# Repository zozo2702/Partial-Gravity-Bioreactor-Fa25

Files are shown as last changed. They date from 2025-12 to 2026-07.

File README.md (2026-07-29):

# Partial Gravity Bioreactor Simulation

A computational simulation of a partial gravity bioreactor system designed to model biological behavior under reduced gravity conditions.

🏆 Developed as a **Senior Design Project (1st Place Winner)**

---

## Overview

This project focuses on simulating how cells and biological systems behave in environments where gravity is altered, such as in space or rotating bioreactor systems.

The model incorporates:

* Rotational dynamics
* Gravity vector manipulation
* Mathematical modeling of system behavior

## Key Features

* Simulation of partial gravity conditions
* Mathematical modeling of rotational systems
* Data visualization of system behavior
* Modular code structure for experimentation

## Applications

* Space biology research
* Tissue engineering
* Bioreactor design optimization
* Microgravity simulation studies

## Authors

** Zenub Abouzid- Led simulation and mathematical modeling of the system
** Irene Bui- Experimental design
** Jake Fisher- SolidWorks (CAD)
** Dmitry Hackel- Hardware construction

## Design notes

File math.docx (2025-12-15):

To construct the prototype, specific calculations must be performed. These calculations will be utilized for simulation purposes to validate the prototype. To generalize the calculation, the specimen will be referred to as a particle; however, this term also applies to cells and the samples used during validation. Due to the numerous considerations involved in the calculation, the process will be divided into five sections: the inclined plane, sedimentation velocity, angular velocity, revolutions per minute, and cellular portion.

### Incline Plane

The inclined plane facilitates the reduction of the gravitational force exerted on a particle by decomposing it into components. The gravitational force is entirely on one axis when

$$ \theta= 0^\circ \text{ or } 90^\circ $$

or decomposed into components. Utilizing trigonometry, Eq. 1 and Eq. 2 illustrate the values for the parallel and perpendicular components of gravity relative to the plane.

$$ g_{\parallel y}= g \, \sin \theta^\circ (1) $$

##### Equation 1. Parallel Gravitational Component

Where:

$$

g_{\parallel y}= \text{gravitational component parallel to the plane}

$$

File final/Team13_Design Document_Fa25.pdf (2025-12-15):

I

# Temple University

## College of Engineering

## Bioengineering

## Design Document

## Partial Gravity Bioreactor

## Presented By: Team #13

Dmitry M Hackel | Irene Bui
Jake Fisher | Zenub Abouzid

## Supervised By:

## Dr. Yah-el Har-el & Dr. Peter Lelkes

1 2 | – | 0 8 | – | 2 025

II

## Acknowledgment

We want to extend our most profound appreciation to the following individuals and organizations who have contributed to the completion of this project:

- Dr. Jonathan Gerstenhaber, for providing valuable information on previous prototypes, coding, debugging, and ideas that paved the way for the prototype, and for delivering his lab time and office hours for us to finalize our prototype.
- Dr. Michael Phelan, for allowing us to use his air-bubble-bioreactor
- Dr. James Furmato, for allowing us to use the laboratory during his lectures.
- PhD Candidate Jennifer Patten and PhD Student Shaylyn Westmoreland, for providing the materials in the lab and being present to supervise the laboratory validation test.
- Brian Amin and Matthew Short, a previous team who completed a similar topic, for giving us the time to explain their prototype in more depth.
- Ahmed Satour and Muhammed Hassan, for aiding in the program.
- The 2nd floor mechanical shop, lab coordinators, and students who kindly helped us with the issues faced during the build.
- Temple University, for providing access to their machines, labs, and space.

Additionally, we would like to express our gratitude to all those who have supported us in both visible and unseen ways. Without your contributions and presence, this project would not have been possible.

Thank you.

III

## Abstract

The progress of human exploration to space, the Moon, and Mars is not considered safe because of the limited understanding of how partial gravity impacts human cells. This issue has not been fully addressed due to cost limitations and the lack of validation of partial gravity on Earth. This project focused on developing a validated prototype for a partial gravity bioreactor. By successfully simulating the mathematical model and conducting tests to validate the prototype, a better understanding of whether partial gravity is achieved and its limitations can be discussed.

IV

# Table of Contents

## LIST OF ACRONYMS/ABBREVIATIONS | VI LIST OF FIGURES | I LIST OF TABLES | II

V

VI

### List of Acronyms/Abbreviations

MOND | Modified Newtonian Dynamics
ACME | Advanced Combustion via Microgravity Experiments
NASA | The National Aeronautics and Space Administration
ISS | International Space Station
0G | Zero Gravity
µG | Microgravity

1
6 G | Lunar Gravity

3
8 G | Martian Gravity
1G | Earth Gravity
RWV | Rotating Wall Vessel
UNSDG | United Nations Sustainable Development Goals
SDG | Sustainable Development Goals
DGD | Degree of Gravity Dispersion
RGP | Reduced Gravity Paradigm
STLV | Slow-Turning Lateral Vessel
HARV | High Aspect Ratio Vessel

MAGICIAN Mars Artificial Gravity Habitat with Centrifugation

I

### List of Figures

II

### List of Tables

# 1. Problem Statement

## 1.1 Overall Objective

Since the 1960s, space exploration has yielded intriguing discoveries that continue to unfold. Yuri Gagarin became the first human in space in 1961, paving the way for thousands of astronauts and cosmonauts to follow him as the years passed [1]. Various theories have been proposed based on space, including the Croatian Barrel Theory, which explains how the solar system, stars, and other celestial bodies formed [2], [3]. In 2002, research refuted the theory that gravity alone governs the universe, as it could not explain specific astronomical observations [4]. Sanders and McGaugh modified Newtonian gravity as an alternative to cosmic dark matter, known as Modified Newtonian Dynamics (MOND), correlating the Newtonian acceleration with the observed acceleration at any radius in a galaxy [5], [6].

Exploring space not only reveals discoveries beyond our planet but also uncovers truths that shape and govern our lives. Advanced Combustion via Microgravity Experiments (ACME) investigates fuel efficiency and pollutant production in combustion under microgravity conditions on Earth [7]. One of their investigations, Flame Design, studied the quantity of soot produced under different flame conditions [7]. Such a discovery could lead to more efficient combustion, reducing pollution on Earth [7]. In the ongoing Moon exploration, researchers found that the Moon's gravity affects Earth’s tides, plant growth, animal behavior, and agricultural practices [8]. Moreover, models have shown that the Earth-Moon coupled magnetospheres provide a buffer against the solar wind, allowing for a reduction in Earth’s atmospheric loss to space [9]. The National Aeronautics and Space Administration (NASA) has been exploring Mars for over sixty years to decide whether it is or was a habitable world [10]. Since Mars is the most similar planet to Earth, understanding its surface and evolution is crucial for preparing for future human exploration [11]. With evidence suggesting that Mars was once full of water, warmer, and had a thicker atmosphere, it is highly likely that Mars could be a habitable environment [11].

Traveling beyond Earth’s atmosphere to investigate potential extraterrestrial life entails considerable risks and substantial financial investment. Given that human physiology is heavily dependent on gravity, significant fluctuations in the gravitational force may lead to serious health issues [12]. Gravity, as a vector quantity, influences all objects by determining their weight relative to their mass [13]. Biological organisms respond to environmental stimuli—including gravity—by developing unique morphological traits, physiological characteristics, behaviors, and habitat preferences [13]. The sensitivity of organisms to changes in gravity increases with their size and mass, with single cells enduring exposures up to 10⁵G and humans tolerating gravitational forces of 4-5G [13]. At the cellular level, cells comprise organelles, each with mass and thus subject to gravitational forces [14]. Variations in gravitational vectors could disrupt cellular homeostasis, affecting structural integrity, composition, and orientation, such as the cytoskeleton, which maintains cellular shape [14]. Additionally, numerous studies have documented genes that are sensitive to gravity alterations, including alterations in cytoskeletal gene expression pathways and gene inhibition following microgravity exposure [15], [16]. In the absence of gravity, cellular growth pathways shift, and metabolic processes adapt due to changes in reactive oxygen species levels [17], [18].

Furthermore, cellular adaptation to gravity is crucial for tissue adaptation, as bones contain osteocytes that sense and respond to varying gravitational loads [13].

Such cellular changes impact the entire human system. Astronauts exposed to microgravity undergo physiological deconditioning in systems sensitive to mechanical loading, including the cardiovascular, pulmonary, and musculoskeletal systems [19]. To mitigate these effects, International Space Station (ISS) crew members engage in rigorous exercise; however, despite extensive physical activity, astronauts still return from their six-month ISS missions exhibiting decreased calf muscle volume and strength, loss of bone mineral density, and reduced peak oxygen uptake [20], [21], [22], [23].

Given that, it is highly unethical to send people into space without understanding the effects of gravitational changes on the body. This paper discusses a validated prototype of a device that cultures cells under partial gravity and microgravity, enabling the correlation of specific cell behaviors with gravitational conditions.

## 1.2 Background

Understanding the effects of partial gravity on humans is less well studied due to the high costs of conducting tests in partial or microgravity environments. Between 1960 and 1973, the research experience and studies gained during the Apollo missions—focused on lunar exploration—provided valuable insights into the diverse effects of partial gravity on the human musculoskeletal, cardiovascular, and respiratory systems, employing either microgravity or Earth’s gravity as controls [23], [24]. However, the Apollo missions cost approximately $25.4 billion in 1969, equivalent to roughly $217 billion in 2024 [25]. Following these missions, despite the lack of subsequent lunar landings, the failures in early missions facilitated advancements in spacecraft design, including the incorporation of additional protective layers and the development of new, safer materials, as well as the integration of computer systems for troubleshooting purposes [26]. In 2019, the health impacts of a year-long space mission were examined at both the molecular and psychological levels by comparing the DNA sequences of twin brothers, Mark and Scott Kelly, with Mark Kelly remaining on Earth serving as the control, and Scott Kelly participating in spaceflight [27], [28]. The study revealed that extensive changes in multisystem and gene expression occur during spaceflight [28]. Astronauts may face risks including mitochondrial dysfunction, immunological stress, vascular modifications, fluid shifts, and cognitive performance decline, as well as alterations in telomere length, gene regulation, and genome integrity [28].

Given the costs and decommissioning of the ISS, researchers endeavored to replicate partial gravity conditions on Earth, such as using a pulley-spring system to simulate partial gravity for rodents (see Figure
1) [23], [29]. However, a limitation of the apparatus was that only the tail was suspended rather than the entire body, resulting in a weight shift within the rodent’s body and thus failing to provide a truly accurate simulation [29].

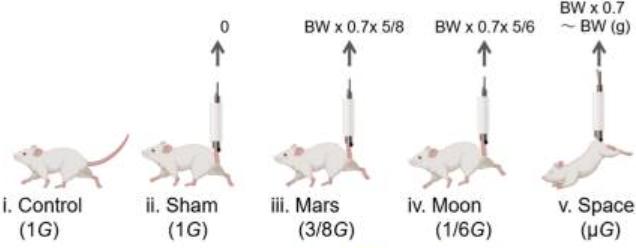
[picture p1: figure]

Figure 1. Experimental Design for Simulated Partial Gravity Apparatus for Rats
The figure shows the groups of experimental rats with (i) the Control group (1G); (ii) the sham group with SA (1G); (iii) the Mars group (³
8

G); (iv) the Moon group (¹
6

G); and (v) the interplanetary space (µG) group [29].

The effects of gravity on an object may manifest as either displacement or deformation [30]. Microgravity creates distinctive environments conducive to cell growth, whereas partial gravity (such as on the Moon and Mars) may yield markedly different effects [31]. To comprehensively understand the concepts related to partial gravity apparatuses, it is imperative to distinguish between zero gravity, gravity, microgravity, and partial gravity. Gravity is an abstract phenomenon that can be quantified; however, its fundamental cause remains unknown [32]. The gravitational constant is not a force or acceleration but is employed as a scaling factor in Newton's Law of Gravitation, as demonstrated in Equation 1[32], [33].

F =

Gm1m2
r

2

(1)

Equation 1. Gravitational Force Equation

Where:
F = gravitational force
m1 = mass 1
m2 = angle between the inclined plane and the base r = distance between masses
G | = universal constant (6.67384 ∗ 10⁻¹¹ m³ s
| 2 kg

)

Zero gravity (0G) describes a condition where there is an absence of gravitational force exerted on an object, which occurs either due to its infinite distance from any other gravitational body or when the net sum of all forces acting upon it equals zero [34]. Microgravity (μG) pertains to a state in which the net gravitational force exerted on an object is minimal, typically within the range of 10⁻⁴

to 10⁻⁶G [35].
Although the object remains under the influence of gravitational forces, it continues to undergo free fall [35]. This perpetual free fall occurs when an object falls at a constant velocity without contacting a surface [35]. As a result, the difference between the initial and final velocities manifests as a constant acceleration (g) [35]. Partial gravity refers to a gravitational force that is diminished but not absent compared to Earth's gravitational acceleration, such as on the Moon, where gravity is approximately 1
6

G, on Mars 3
8

G, and on

Earth 1G [27]. On Earth, partial-gravity simulation can be achieved using techniques such as centrifugation, parabolic flight, or modified rotation devices that generate accelerations below 1 g [36].

To investigate gravitational effects, cell culturing is regarded as the most efficacious method, with bioreactors serving as the optimal apparatus, given their ability to supply controlled nutrients and biomimetic stimuli for cellular growth [37]. A bioreactor is defined as a vessel in which a chemical process involving organisms or biochemically active substances derived from such organisms is conducted, or a system designed for cell cultivation, first developed in 1964 (refer to Figure 2).

Figure 2. Basic Bioreactor

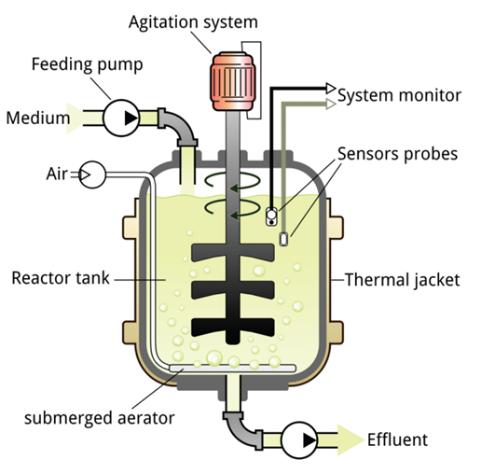
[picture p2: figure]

The figure shows the basic components of a bioreactor. It includes a feeding pump, air, medium, an agitation system, a reactor tank, and other elements to ensure an automated culturing system.

Previous bioreactors were designed as ground-based systems to mimic aspects of weightlessness or reduced gravity experienced by biological organisms in space. Recognizing this potential, in the mid-1980s, NASA researchers at the Johnson Space Center needed to develop a method to study the effects of microgravity on human tissues, as the shuttle fleet was grounded following the Challenger disaster [38]. They invented a rotating bioreactor to address the challenge of treating injured astronauts in space and to simulate weightlessness on Earth [38]. In μG, the bioreactor enables cells to grow in three-dimensional tissue structures that closely resemble natural development, facilitating advances in medicine both on Earth and in space [38]. In 2002, Houston-based Regenetech Inc. licensed NASA bioreactor technology and patents that can expand adult stem cells (from blood to bone marrow) by 50-200 times in less than a week, providing safer, faster, and more affordable cell sources for therapies [38].

Partial gravity bioreactors, although not extensively studied, have been previously examined. Research dating back to the 1900s has investigated the effects of clinostats, or rotating wall vessels, on biological samples [39]. Clinostats were invented by Julius Sachs, who rotated growing plants around their growth axis [39]. These devices exist in one-dimensional (1-D) or two-dimensional (2-D) forms, depending on the dimensions of the rotated axial line or the entire experimental area [40]. Subsequently, enhancements to the clinostat with two axes led to the development of three-dimensional (3-D) clinostats, known as the Random Positioning Machine (RPM) (refer to Figure 3) [40], [41].

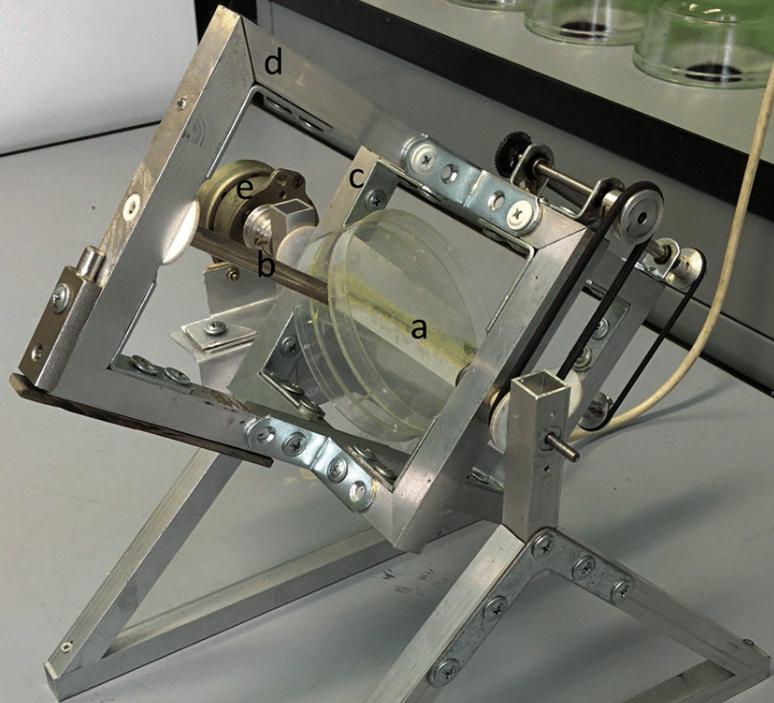
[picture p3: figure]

Figure 3. 3D Clinostat
The figure depicts a three-dimensional clinostat employed to investigate the effects of microgravity on seed germination: (a) insert for Petri dishes; (b) rotating shaft; (c) inner frame; (d) outer rotating frame; (e) motor [41].

Numerous early-stage partial-gravity bioreactors have been investigated using plant species capable of continuous growth under Earth's gravity [42]. Initial implementations included clinostats, which maintain a constant rotation of a sample to average the gravitational vector to near zero, effectively [39]. This partial gravity bioreactor does not fully replicate “true” microgravity, as cells continue to experience mechanical stimulation and gradients that differ from those in actual microgravity conditions [39]. Subsequently, rotating wall vessel (RWV) bioreactors were introduced as a specialized variant of clinostats [39]. RWVs are fluid-filled cylinders containing cells, designed to create a low-shear, controlled environment conducive to cellular differentiation in three-dimensional space [43]. By rotating at a terminal velocity, RWVs facilitate the proper delivery of nutrients to the tissue culture, thereby promoting healthy tissue and cell growth [45]. (https://www.nature.com/articles/nm0898-901) In 2018, a previous senior design team utilized the stability of RWVs for cell culturing while incorporating the partial gravity factor using an inclined plane to partially cancel the gravitational vector, allowing cells to experience a form of partial gravity (refer to Figure 4).

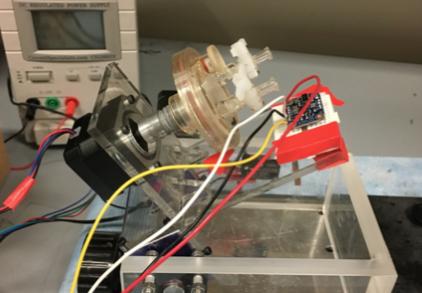
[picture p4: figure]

Figure 4. Partial Gravity Bioreactor
The figure depicts the prototype of a partial gravity bioreactor, designed by an earlier senior design team. It comprises an RWV affixed to an inclined plane that simulates partial gravity.

## 1.3 Needs Statement

There is a need to build a validated partial gravity cell-culturing prototype that would enable us to study the relationship between cell properties and different gravitational environments, thereby allowing us to correlate gravitational differences with cell properties.

## 1.4 Implications of Project Success

If the prototype succeeds, both terrestrial and extraterrestrial life would benefit significantly. Understanding the effects of varying gravitational conditions on cellular behavior would enable more precise conclusions about human space exploration. Such findings would underpin the development of solutions to safeguard human safety beyond Earth. Facilitating human travel to outer space, including destinations such as Mars and the Moon, enhances our understanding of extraterrestrial regions and addresses fundamental questions about alien life. Additionally, this research has the potential to identify new planets or locations in space where humans might establish a new life.

The success of the prototype closely correlates with several United Nations Sustainable Development Goals (UNSDGs) [44]. SDG 3: Good Health and Well-being is supported, as the device facilitates controlled studies on how partial gravity influences cellular development, physiology, and long-term health in space [45]. By understanding these effects, the prototype can inform the design of countermeasures, treatments, and potentially therapeutic approaches for conditions such as bone loss and muscle atrophy, which are of critical concern for astronauts [28]. Accordingly, the prototype would help ensure healthy lives for humans [45]. Furthermore, SDG 9: Industry, Innovation, and Infrastructure is pertinent, as the development of the prototype constitutes an innovative research platform that represents the convergence of biotechnology and space technology [46]. Additionally, the prototype advances SDG 12: Responsible

Consumption and Production by implementing a closed-loop biological system, an approach essential for sustainable space habitats and beneficial for the efficient utilization of resources on Earth [47]. The use of a bioreactor enhances system control during cell cultivation, enabling accurate, real-time monitoring, early problem detection, reproducibility, and cost efficiency [48]. In this context, SDG 13: Climate Action is addressed by demonstrating how biological systems adapt to extreme and changing environments, thereby informing strategies for Earth's ecosystems [49].

# 2. Design Criteria

To guarantee the feasibility of the prototype, the design criteria are classified as either non-negotiable (mandatory) (refer to Table 1) or negotiable (desirable) (refer to Table 2). However, owing to the complexity of the project, these criteria are divided into two primary domains: partial gravity and the prototype.

## 2.1 Non-Negotiable Criteria

Three criteria must be satisfied to deem the partial gravity component in the project successful: gravitational type, uniform trajectory, and mathematical simulation.

Gravitational Type: With NASA deorbiting the ISS, the ability to conduct experiments in the unique microgravity laboratories would be impossible. Therefore, gravitational experiments conducted on Earth should encompass the primary missions previously planned. According to NASA, traveling to the lunar surface and around the Moon would facilitate scientific discoveries that prepare humans for subsequent exploration, including Mars [50]. As the Moon and Earth represent the two most significant gravitational environments, lunar gravity (¹
6

G) and Martian gravity (³
8

G) warrant careful consideration [51]. To obtain

more accurate data, Earth’s gravity (1G) and microgravity (μG) should also be included to ensure that the same cells are subjected to all gravity levels and to serve as references for previous experiments [51].

Uniform Trajectory: To cultivate cells effectively, the partial gravity method should not present any issues for cell culture practices. Given cells' high sensitivity to their environment, the technique used to simulate partial gravity must prevent excessive vibrations or inconsistent cell motion [52]. To accomplish this, the procedure for attaining different gravitational levels should function smoothly, enabling cells to undergo free fall while simultaneously minimizing shear stress on the cells and maintaining these conditions continuously.

Mathematical Simulation: The partial gravity effect on cells has not yet been observed or tested. However, visualizing gravity is not applicable, since gravity is a theory [53]. Utilizing mathematics, fluid mechanics, and particle mechanics, a mathematical model should be developed for partial gravity.

Four criteria should be met to consider the prototype successful: overall device size, electrical safety, emergency safety, and material.

Overall Device Size: Since the prototype's placement may be limited to the incubator, its overall dimensions are also constrained. The Nuaire NU-5810E incubator is considered the most suitable and effective location based on previous designs because it operates at 37°C with 98% humidity [54]. The maximum size of the prototype is limited by the incubator's internal capacity, which measures 23 × 17 × 14 in.

Electrical Safety: For electrical safety, the standards established by the International Electrotechnical Commission (IEC), specifically IEC 60204-1, which outlines the general requirements for electrical equipment of machines (related to the safety of machinery), will be followed [55]. According to 'Safety of Machinery - Electrical Equipment of Machines - Part 1: General Requirements’, a protective bonding circuit is required, ensuring all exposed metallic parts of the machinery are bonded and connected to a reliable ground [55]. This includes electrical enclosures and wiring, which should be organized neatly, clearly labeled, and protected, with cables rated appropriately for the voltage and current they carry [55]. Complying with EN 61010-2-030, Measuring Circuits and Test Equipment Safety Test, ensures the standard is met [56]. Since this is a prototype, comprehensive documentation—including electrical schematics, wiring diagrams, component lists, and user manuals—is essential.

Emergency Safety: As the prototype involves mechanical motion, there exists a potential for malfunctions. Consequently, ensuring the machinery's safety is imperative. The International Standard ISO 13850, titled "Emergency Stop Function, the Design Principles for the Emergency Stop Function on Machinery", stipulates that an emergency stop is mandated when the machine presents a risk, and its implementation would mitigate this risk, as applicable to the prototype [57]. To comply with this standard, the emergency stop function should be activated by a human-initiated signal that remains engaged until it is manually reset [57]. Additionally, no start command should be effective during the operations halted by the emergency stop initiation, which must likewise be reset through human intervention [57].

Material: Given the potential placement of the prototype within an incubator, the selected materials must withstand room temperature, 37°C, and 98% humidity [54]. Furthermore, the prototype is expected to remain stable for safety concerns.

Table 1. Non-Negotiable Needs

# | Priority | Requirement | Metric | Target Values/ Range or Pass/Fail | Justification

1 | Non-negotiable | Gravitational Type | Partial Gravity and Controls | Range: μG to 1G Lunar gravity (¹ G) 6 Martian gravity (³ G) 8 Earth’s gravity (1G) Microgravity (μG) | NASA’s Goals [50]
2 | Non-negotiable | Uniform Trajectory | Partial Gravity Accuracy | Pass/ Fail Using Model and Visuals | Inaccuracy of data due to cell sensitivity [52]
3 | Non-negotiable | Mathematical Simulation | Mathematical Model | Pass/ Fail | Accuracy and Validation
4 | Non-negotiable | Overall Device Size | Dimensions | 23 × 17 × 14 in | Nuaire NU-5810E Incubator Restricted Area [54]
5 | Non-negotiable | Electrical Safety | Safety | Pass/ Fail of EN61010-2-030 | IEC 60204-1 [55, p. 60]
6 | Non-negotiable | Emergency Safety | Safety | Pass/ Fail of ISO 13850 | ISO 13850 [57]
7 | Non-negotiable | Material | Strength, Durability, and Sterility | Pass/ Fail to withstand room temperature and 37°C, along with 98% humidity [54] | Safety

The table outlines the seven non-negotiable criteria essential for validating the prototype. Regarding partial gravity, the requirements encompass gravitational type, uniform trajectory, and mathematical simulation. Regarding the prototype, the requirements related to the base and partial gravity—such as overall device size, electrical safety, emergency safety, and material—are considered fundamental. Additionally, the metric, target range, and justification for each criterion are systematically provided.

## 2.2 Negotiable Criteria

Regarding the negotiable criteria, three factors could enhance the prototype if implemented. First, ensuring that the materials in contact with the cells are non-toxic would ensure that the prototype is suitable for cell culturing, with a cell viability exceeding 80%, in accordance with ASTM F2739-19 [58]. Additionally, integrating an automated imaging system for cellular analysis would enable users to comprehensively evaluate cell culture and gain deeper insights into cellular interactions across different temporal stages. Finally, advancing mathematical models into computational simulations would facilitate a more detailed understanding of the fluid dynamics affecting cells.

Table 2. Negotiable Needs

Priority | Requirement | Metric | Target Values/ Range or Pass/Fail | Justification
Negotiable | Cell Viability | Proper Cell Culture | >80% | ASTM F2739-19 [58]
Negotiable | Automated Imaging System | Data Tracking | > 30 FPS | To record the cell’s activity during culturing
Negotiable | Computational Models | Modeling Accuracy | Pass/ Fail | To have a more sophisticated model for partial gravity

The table outlines the three negotiable criteria for enhancing the prototype. These criteria encompass cell viability, an automated imaging system, and the development of computational models. The table supplies the metric, target range, and justification for each criterion.

# 3. Solutions

The project focuses on validating partial gravity by ensuring the tested specimen experiences the intended gravitational force. Cell culturing methodologies will not be addressed. To eliminate any effects attributable to cell culture, the same culture component will be used across all proposed solutions.

## 3.1 Bioreactor Solutions

Bioreactors are the predominant method used in cell cultivation due to their ability to sustain biologically active environments and regulate parameters such as pH, temperature, oxygen tension, media perfusion rate, as well as their capacity to apply external stimuli [59]. Various types of bioreactors exist, including wave motion, stirred-tank, and rotating-wall vessels (refer to Supplementary Table S1) [37]. Since cells are susceptible to mechanical stresses such as shear forces and microfluidic flow, which may result in cellular structural failure and reduced viability, the selection of a bioreactor should be based on its ability to exert minimal shear stress on the cells [60]. Cells cultured in microgravity and ground-based microgravity analogs are presented with a low-shear stress environment suitable for cell cultivation [61]. RWVs are effective for small volumes (< 10 L) and can simulate microgravity with low turbulence and minimal impact [37].

Given the same bioreactor used for cell cultivation, two potential RWV configurations are examined. The solutions are based solely on the RWV's bubble issue.

### Solution R.A: Standard Bioreactor

RWVs have been observed extensively to provide continuous particle sedimentation through a culture medium [62]. The rotation provided by the RWV is special since it induces minimal cellular shear and turbulence [62]. Figure 5 shows the side view of a rotating wall vessel [63].

Figure 5. Schematic Side View of Rotating Wall Vessel Bioreactor

The rotation facilitates the complete immersion of the particle seeded in the medium. Consequently, using the standard RWV advances knowledge in cell culture. RWV systems have demonstrated success in cultivating prostate organoids, liver tissue, colon carcinoma, cartilage, and many other cell types [63].

### Solution R.B: Bubble Catcher Bioreactor

One complication associated with RWVs is the formation of bubbles during operation [64]. The formation of bubbles interferes with the RWV environment, which includes zero headspace, low shear, and simulated microgravity [64]. Laminar flow must be established so that the liquid in the bioreactor behaves as a rotating body. A novel bubble-capture HARV design would reduce and potentially eliminate the common issues of bubble formation while also reducing operational media volume without compromising the radius.

The bioreactor is designed with a hollow, microporous plastic tube and an exit channel to capture bubbles (see Figure 6). The small, hollow tube, made of sponge-like plastic with tiny pores, has a plug placed partway down its length. When media is pushed down the tube, an exchange of old and new media occurs, providing nutrients to the circulating cells. This unique design enables direct filling of the main bioreactor chamber, with the output routed through a channel that captures bubbles and facilitates the exchange of used media (as shown in Figure 7) [64].

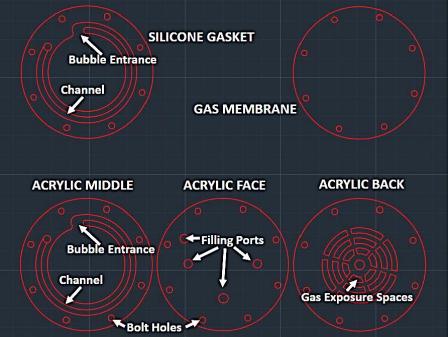
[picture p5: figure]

Figure 6. Design of Bioreactor

Figure 7. Bubble Trapping Bioreactor Sketch

Although this bioreactor design is more optimal, it can be successful only if the bioreactor is built and proven not to sustain any significant issues during construction within the short time available for this project. Furthermore, bubbles or flow disruptions do not simply represent mechanical inefficiencies; they directly affect cells' ability to remain in suspension, receive nutrients, and obtain oxygen. The presence of bubbles can also increase the shear forces affecting the cells.

## 3.2 Partial Gravity Solutions

Regarding partial gravity, three potential solutions are examined.

### Solution P.A: Inclined Plane (Dual Motors)

The proposed solution entails enhancing an existing design by developing a partial gravity prototype using an RWV on an inclined plane, equipped with a dual-motor system (refer to Figure 8). The use of the inclined plane was previously studied and found to be a successful simulation of lunar gravity [65]. The design consists of three components: a foundational structure, a component that securely holds the bioreactor and the motor that generates rotational force, and a final system that adjusts the angle of the motor and bioreactor to simulate partial gravity.

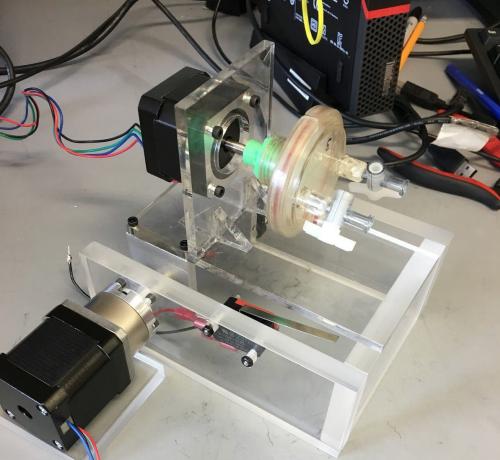
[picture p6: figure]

Figure 8. Inclined Plane Bioreactor with Dual Motors
The figure depicts the inclined-plane bioreactor designed by the previous senior design team. Utilizing two motors and an inclined plane, the previous team simulated partial gravity.

The base will be constructed as a rectangular structure capable of supporting the bioreactor assembly with stability and durability. The main section of the RWV will include a motor attached to the bioreactor to enable rotation, and this assembly will be mounted to the system that adjusts the bioreactor's angle. Next, a camera will be mounted on the same part of the device to accurately simulate the bioreactor's angle and monitor the cells during rotation within the RWV. For the final part, a secondary motor capable of adjusting to various angles will be used and attached to the bioreactor system. The secondary motor should be able to set angle variations at least at four different positions to mimic the following gravitational conditions: 1G,

3
8

G,

1
6

G, and µG. The rough sketch of the proposed solution is seen in Figure 9.

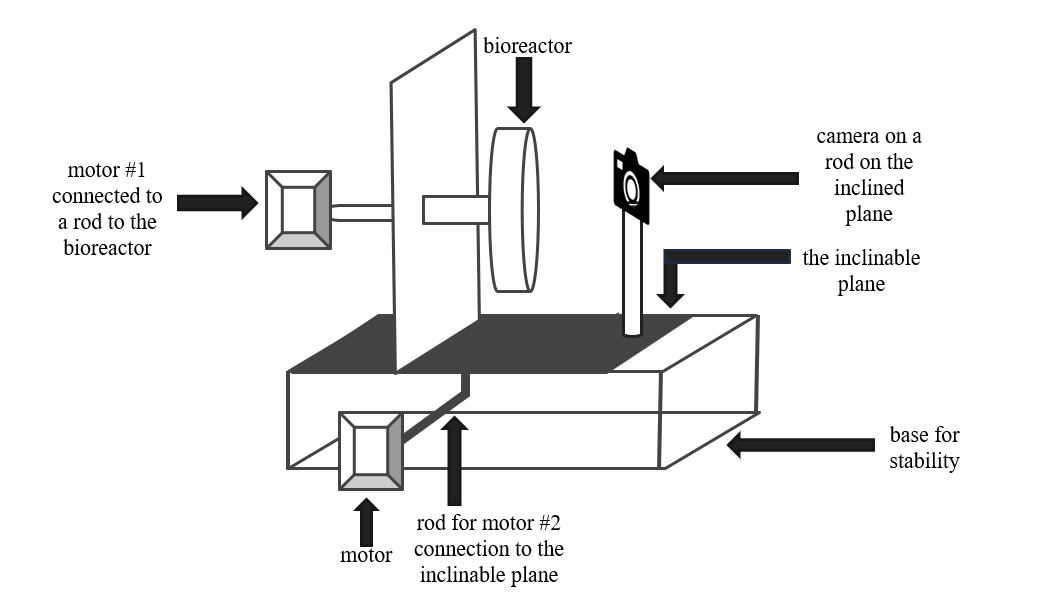
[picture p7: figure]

Figure 9. Rough Sketch of Inclined Plane with Dual Motors
The figure illustrates the preliminary sketch of the inclined plane setup with dual motors. The bioreactor is affixed to one motor, while the inclined plane is connected to another motor. The camera is positioned parallel to the bioreactor to ensure the entire bioreactor is captured in view.

These improvements to the current designs enhance the ability to validate the actual generation of partial gravities. The addition of a camera will enable real-time, accurate observation of cell reactions. Furthermore, this design provides a means for validation through modeling and mathematical analysis to confirm that this configuration produces the desired partial gravity effect for RWV.

### Solution P.B: Four Centrifugations

The proposed solution concentrates on the centrifugation concept to emulate partial gravity on biological cells. The rationale for employing centrifugation is that centrifugal force generates an apparent gravity during rotational motion [66]. In fact, a proposed 0.16G acceleration was achieved by connecting two modules via a 300-meter tether and rotating them at 1 rpm [67]. O’Neill’s 1.8 km radius Stanford torus, spinning at 1 rpm, produced Earth’s gravity in space [67]. However, in numerous other examples and proposed solutions, the relationship between rotation and radius is closely interdependent. The centripetal acceleration is inversely related to the tangential velocity when the tangential velocity remains constant, but is directly related when the angular velocity remains constant [68]. Consequently, centrifugation is a valid method for generating partial gravity, which can be as low as 0.001G [69]. However, during centrifugation, it is crucial to rotate the system around its own axis to prevent sedimentation, as shown in Figure 10 [70].

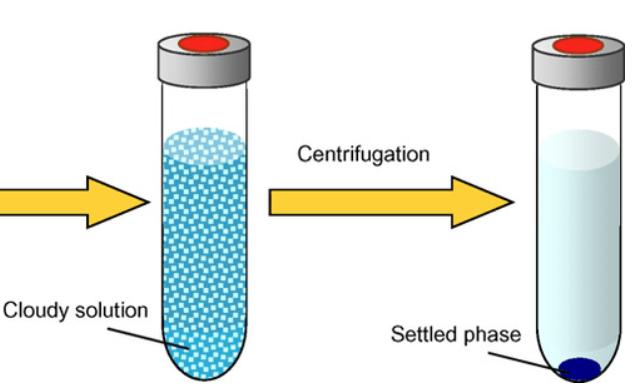
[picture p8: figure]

Figure 10. Schematic Diagram of Centrifugation to Settle Particles

The proposed solution emphasizes the ability to use a set of rotating bioreactors tailored to specific gravitational forces. As the system encompasses four distinct gravity levels, the solution entails four separate bioreactors, each stabilized with its own diameter. These bioreactors would feature varying radii, enabling the simulation of partial gravity without subjecting the cells to undue shear stress from rotational motion and friction within the medium. Additionally, each bioreactor would be equipped with its own motor. Regarding the observational equipment, a camera will be positioned to provide a frontal view of all bioreactor surfaces, extending from the base of the prototype in an L-shaped configuration to encompass all units. Figure 11 illustrates the overall design schematic.

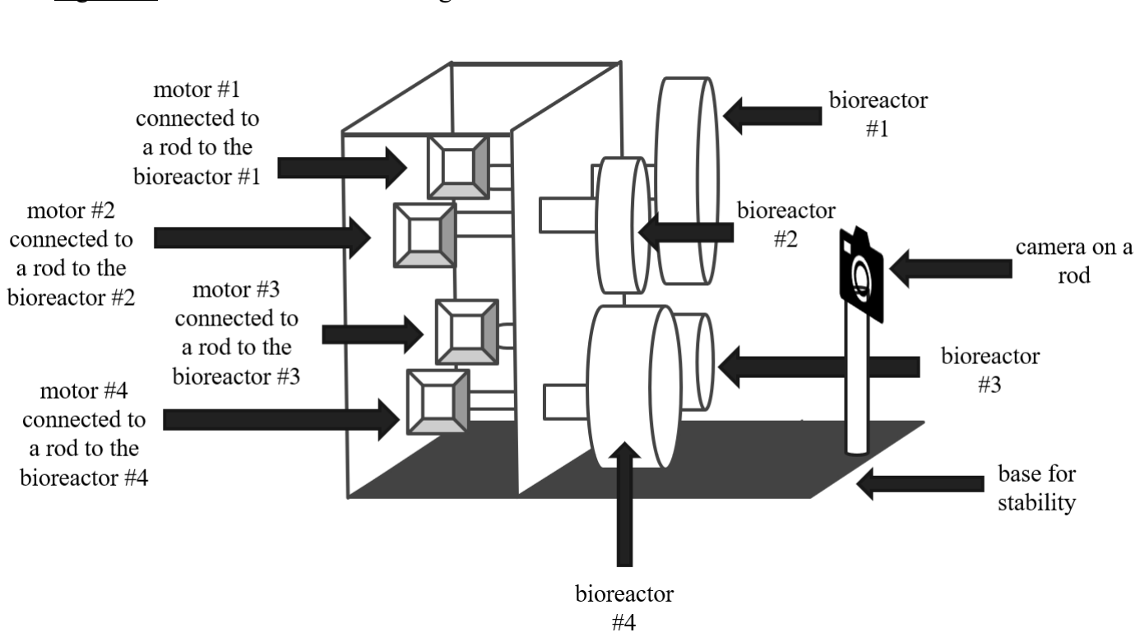
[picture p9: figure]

Figure 11. Rough Sketch of the Centrifugation Solution
There are four different bioreactors with different diameters, each attached to a motor. All the bioreactors are held in place by a vertical plane. The camera is placed to view the whole circumference of all the bioreactors.

### Solution P.C: Inclined Plane (Single Motor)

This proposed solution outlines the use of an inclined-plane single-motor bioreactor equipped with an integrated camera monitoring system as an innovative approach to enhancing the efficiency of cell culture processes. The system is engineered to optimize mixing, oxygen transfer, and gentle agitation—all vital for the proliferation of cells in suspension under partial gravity conditions. These hydrodynamic parameters can be quantified using specific power input (P/V), which correlates motor power with culture volume and serves as an essential metric to ensure proper mixing while preventing excessive shear forces. By maintaining P/V within the ranges established for mammalian and microbial culture systems, the design aims to balance nutrient and gas transfer requirements while safeguarding sensitive cell cultures [71].

For real-time visualization, the system will incorporate a camera with adjustable focus and LED illumination to ensure uniform brightfield imaging. To maintain consistent image quality during bioreactor operation, the camera shall be mounted directly to the rotating vessel assembly, thereby following the vessel’s motion and orientation changes. This methodology ensures the camera maintains a constant field of view relative to the culture. The camera is affixed using a gimbal-like (think of a movable selfie stick) system, which keeps the lens aligned with the observation window throughout the entire range of vessel motion.

The bioreactor's control is handled by a microcontroller platform, such as an Arduino, which regulates motor speed, acquires sensor data, and operates the camera. Data logging facilitates the export of sensor readings and image sequences for subsequent analysis. Safety features include overcurrent protection, temperature cutoffs, and emergency stop mechanisms to ensure the safety of both the vessel and its cultural contents.

The rotation and tilt operation using a single motor effectively facilitates controlled vessel rotation; however, it offers limited flexibility in adjusting the vessel's angle. In the simplest configuration, the motor drives the vessel at a fixed RPM, while the axis of rotation remains stationary; the angle relative to gravity is mechanically preset on the mounting frame. This configuration indicates that the speed and angle cannot be adjusted simultaneously, as the motor can execute only one function at a time. More sophisticated systems, such as differential gears, could be implemented; however, they introduce additional mechanical complexity, thereby reducing overall efficiency [71]. A rough sketch of the solution is seen in Figure 12.

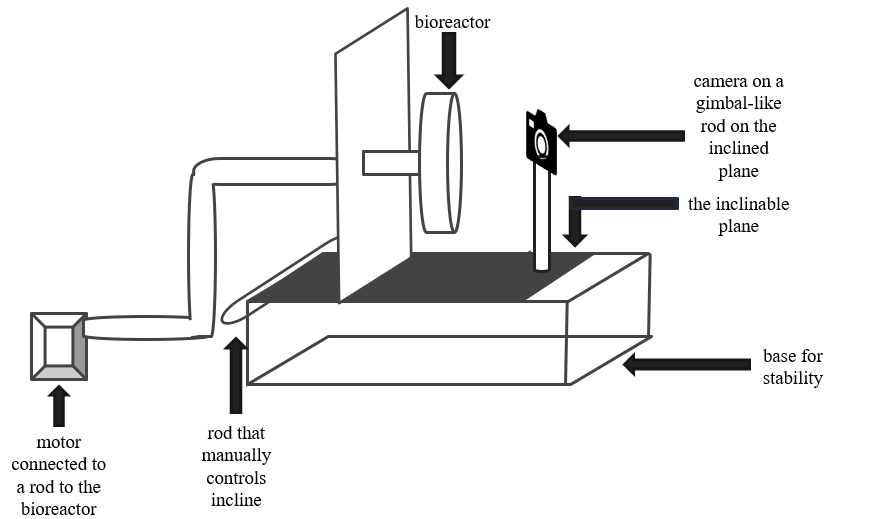
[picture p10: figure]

Figure 12. Rough Sketch of Inclined Plane with Single Motor
The figure illustrates the preliminary sketch for the single-motor inclined plane. The bioreactor is connected to the motor via a tube, and the incline plane is adjusted manually.

## 3.3 Decision Matrix

Selecting the appropriate approach for the bioreactor necessitates evaluating multiple factors, including availability, research utilization, and bubble formation. For the partial gravity scenario, the factors considered are gravitational type, overall device size, and design time. Given that each option has its own advantages and disadvantages, a weighted comparison is essential to identify the optimal solution. A prioritization (weighted decision) matrix is employed to evaluate the options based on predetermined criteria [72].

Regarding the bioreactor, the primary criterion to consider is availability. Since this prototype comprises two components, with a particular emphasis on the partial gravity section, the RWV is expected to have a minimal impact on the project timeline. Consequently, this criterion is assigned a score of 5 points. A score of 1 indicates that the component is either not accessible or requires design development. In contrast, a score of 2 means that it is accessible and requires no additional design effort.

The second criterion pertains to the formation of bubbles. Bubble formation represents one of the most limiting factors in data extraction and is therefore assigned a weight of four points. A rank of one indicates that bubble formation is present or disrupts fluid motion, whereas a rank of two signifies that bubble formation does not interfere with the flow of the medium.

Finally, the third criterion pertains to research utilization: the number of literature papers that have employed the bioreactor. If research articles have utilized the bioreactor and data extraction occurred without issues, this suggests that the bioreactor is appropriate for use, or that its disadvantages do not outweigh its advantages. Given that the primary objective is to employ the bioreactor for research purposes, this criterion is assigned a weight of two points. A ranking of 1 indicates minimal use in literature, whereas a ranking of 2 signifies more widespread application. With these criteria established, the decision matrix is accordingly defined.

Regarding partial gravity, the criteria are gravitational type, overall device size, and design time. The primary criterion concerns the gravitational type (see Table 1). Since the main objective is to attain 1
6

G,

3
8

G, 1G, and μG to verify the locations' gravitational properties that NASA is reluctant to explore, the

gravitational type criterion is assigned a weight of 5 points [51], [73]. The ranking of this criterion is based on where such gravitational values can be achieved. A rank of 1 indicates that only those four gravity values are achieved, whereas a rank of 3 signifies that more gravitational values can be achieved.

The second criterion concerns the overall device size (see Table 1). When the device is situated within the incubator, its size is limited by the dimensions of 23 × 17 × 14 in. Nonetheless, due to the design's substantial dependence on the type of bioreactor used and the restrictions on dimension ranking, a score of 2 points is assigned. Consequently, this criterion is assessed based on the likelihood of space utilization, with a ranking of 1 indicating considerable spatial occupation and 3 indicating minimal space consumption.

The final criterion relates to the design timeline. Considering that the project must be completed within three months, the proposed solution must adhere to this schedule. However, due to the materials used in the device's procurement schedules and supply arrival, this criterion shall be assigned a weight of 2 points. The ranking for this criterion is based on the ease of project replication, with 1 indicating a prolonged or unprecedented process and 3 indicating swift completion. Once the criteria are established, the decision matrix is accordingly identified.

After evaluating the criteria for the bioreactor presented in Table 3, the novel RWV bioreactor received the highest score of 20 points. Consequently, the selected bioreactor is the novel model. Upon assessing the criteria for partial gravity, as shown in Table 4, the inclined plane with dual motors achieved the highest score of 23 points. Therefore, the preferred solution is the novel RWV on an inclined plane with dual motors.

Table 3. Design Matrix for RWV Solutions
Criteria | Weight | Standard RWV | Novel RWV
Rating | Weighted Score | Rating | Weighted Score
Availability | 5 | 2 | 10 | 2 | 10
Bubble Formation Disrupts Flow | 4 | 1 | 4 | 2 | 8
Research Usage | 2 | 2 | 4 | 1 | 2
Total Score | | | 18 | | 20

The table displays the criteria and their corresponding weights, which determine the favorable RWV solution. The rating and weighted score for each solution are shown. The novel RWV scored the highest.

Table 4. Design Matrix for Partial Gravity Solutions
Criteria | Weight | Inclined Plane with Dual Motor | Four Centrifugations | Inclined Plane with One Motor
Rating | Weighted Score | Rating | Weighted Score | Rating | Weighted Score
Gravitational Type | 5 | 3 | 15 | 1 | 5 | 2 | 10
Dimensions | 2 | 1 | 2 | 3 | 6 | 2 | 4
Design Time | 2 | 3 | 6 | 2 | 4 | 1 | 2
Total Score | | | 23 | | 15 | | 16

The table shows the criteria and their weights, which determine the favorable partial gravity solution. The rating and weighted score for each solution are displayed. The inclined plane with dual motors scored the highest.

# 4.Engineering Design

The engineering design of the solution is founded on detailed methodologies, calculations, and components to facilitate the successful execution of the partial gravity applied to the cells. This section outlines the theory, calculations, and mechanical design
materials, electronics, and validation strategies used to confirm that the selected options meet the system requirements.

## 4.1 Design Rationale

According to the most essential non-negotiable criteria, the prototype should have the ability to induce at least four different gravitational types: 1G,

3
8

G,

1
6

G, and µG. To simulate partial gravity on Earth, various

methods, such as parabolic flight, centrifugation, or modified rotation devices, could be used [74].

The parabolic flight methodology enables researchers to conduct experiments in microgravity and partial gravity, thereby simulating lunar or Martian environments in line with NASA’s mission objective to facilitate human space exploration [75]. The technique utilized to recreate these conditions involves controlled maneuvers that temporarily induce free fall through the following procedures: pull-up, wherein the aircraft ascends at a steep angle (45º) enabling passengers to experience 1.8G; push-over, whereby, upon reaching the apex of the parabolic arc, the pilot reduces engine thrust, causing all objects inside the aircraft to descend together; reduced gravity, which occurs during the descent when no force acts upon the occupants, creating weightless conditions similar to those in space; and pull-out, where increased engine thrust and leveling out return the aircraft to Earth’s gravity [75]. However, this approach has several limitations, including the short duration of reduced gravity, approximately 20 seconds per parabola, with typical flights comprising between 15 and 30 parabolas [75].

Centrifugation is employed to modify the magnitude of Earth’s gravitational force in accordance with Einstein’s Equivalence Principle, demonstrating that there exists no physical distinction between acceleration due to mass and linear acceleration [76], [77]. Operating a centrifuge at a constant velocity allows the sample to change direction and remain centered during rotation continually [77]. Recognizing that the inertia of the sample and the rotation of the centrifuge collectively generate gravitational effects, the magnitude of this simulated gravity is dependent on the radius of the centrifuge and its angular velocity [77]. Centrifuges are used to mimic microgravity conditions through the Reduced Gravity Paradigm (RGP), which emphasizes responses to the difference between two levels of acceleration [77]. RGP is most effective when applied to a stable and steady system operating at a high gravitational level before reducing the acceleration [77]. Optimal results are observed in systems that respond rapidly; intermediate- and slowresponding systems require more time than the available time interval to achieve the desired gravity level [77].

Given the importance of stability in centrifugation, modified rotational devices, including bioreactors, are evaluated for their efficacy in partial-gravity simulation. Bioreactors are biomechanically active systems engineered to replicate biological conditions by utilizing mechanical means to influence cellular processes through the meticulous regulation of biochemical and physical signals [78]. RWV, which employs vessel rotation to generate low-shear mixing and simulated microgravity within the chamber, is available in two variants: the slow-turning lateral vessel (STLV) and the high-aspect-ratio vessel (HARV), as illustrated in Figure 13 [79]. The differences between these two types include the fact that STLVs incorporate a central cylinder oxygenator and can accommodate larger volumes. In contrast, HARVs are equipped with a gaspermeable member on one of their walls to enhance oxygenation [79].

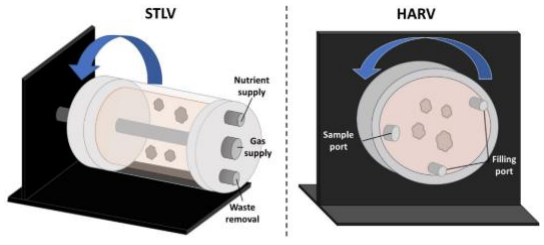
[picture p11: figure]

Figure 13. STLV vs HARV
The figure on the left depicts the STLV bioreactor, with its ports labeled. To the right, the HARV is displayed, also with labeled ports. A cylindrical shape characterizes the STLV, whereas the HARV has a disc-shaped configuration [79].

Despite the limitations associated with the RWV, which include the requirement for high user competency, bubble formation, and the difficulty in determining the appropriate rotational speed to balance solid-body rotation with continuous freefall, the device enhances cellular performance through its capacity to improve mixing in low-shear environments substantially, facilitate high-density cell cultures and selfaggregation, promote cellular differentiation, and, notably, simulate microgravity [80], [81]. The effects of this simulation are well documented, encompassing alterations in calcium handling within cardiac cells and interference with cellular differentiation pathways [82].

The proposed solution emphasizes integrating the benefits of different types of partial gravity simulation while minimizing adverse effects. To optimize cell growth, it is essential to cultivate cells in a manner that simulates free-fall. Consequently, maintaining a constant and steady rotation of the cells is necessary to ensure continuous exposure to free-fall conditions. This objective can be achieved by modifying RWV rotation through the integration of centrifugation methods. As depicted in Figure 14, the device's orbit will be controlled to maintain a low-shear environment, with balanced solid-body rotation and continuous free-fall conditions [83].

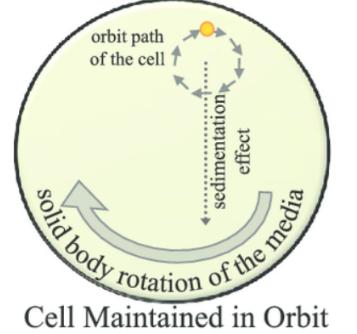
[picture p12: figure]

Figure 14. Orbit Trajectory of the Cell Within a Rotating Bioreactor
The orbital trajectory of the cell within a rotating bioreactor. The sustained rotation and sedimentation effects prevent the cells from settling at the base of the vessel. Additionally, the clockwise rotation of the medium facilitates the continuous suspension of cells in the orbit [83].

However, the centrifugation process would not accurately simulate the partial gravity of 1
6

G and

3
8

G, without affecting cell viability. With the inclination in parabolic flight enabling a 1.8G simulation, the

inclined plane in the solution would serve as the primary mechanism for achieving partial gravity conditions. In fact, NASA is presently constructing a Mars Artificial Gravity Habitat with Centrifugation (MAGICIAN) module to emulate Earth’s gravity on Mars, as illustrated in Figure 15 [84].

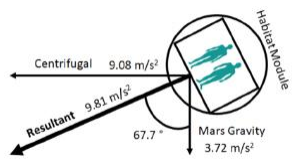
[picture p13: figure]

Figure 15. MAGAICIAN Schematic
A two-dimensional cross-section of the MAGIGAN modules displayed at an angle of 67.7° to achieve a resultant force equivalent to Earth’s gravity [84].

Using a bioreactor would provide a controlled environment for cell growth, thereby reducing the likelihood of inaccurate data resulting from cell culture. Given that the bioreactor's rotation is maintained at a constant rate and the inclined plane's movement is solely a result of gravitational simulation, two motors will be employed.

## 4.2 Calculations

To construct the prototype, specific calculations must be performed. These calculations will be utilized for simulation purposes to validate the prototype. To generalize the calculation, the specimen will be referred to as a particle; however, this term also applies to cells and the samples used during validation.

### Incline Plane

The inclined plane facilitates the reduction of the gravitational force exerted on a particle by decomposing it into components. Referring to Figure 16, the gravitational force is entirely on one axis (when θ° = 0° or 90°) or decomposed into components. Utilizing trigonometry, Eq. 2 and Eq. 3 illustrate the values for the parallel and perpendicular components of gravity relative to the plane [85].

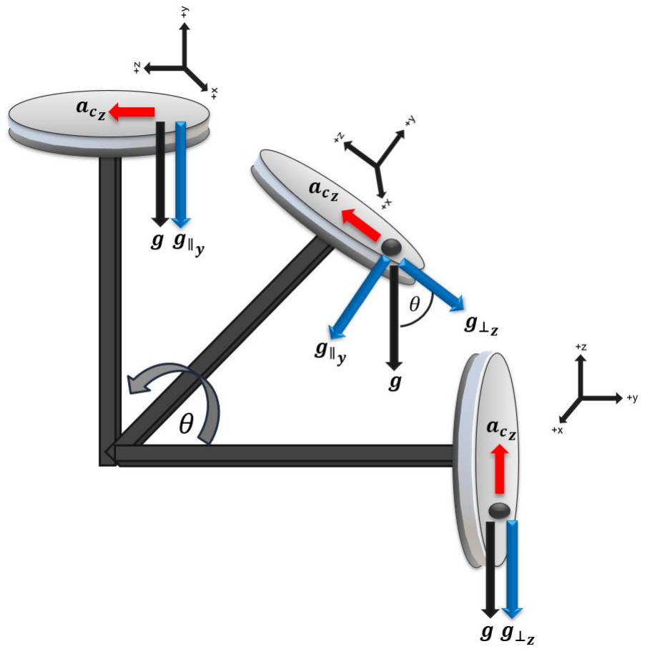
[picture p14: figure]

Figure 16. Free Body Diagram of a Bioreactor on an Inclined Plane
When the plane is parallel to the base, the gravitational force acts in the z-direction. When the plane is inclined at an angle θ from the base, the gravitational force is resolved into components. When the plane is perpendicular to the base, the gravitational force acts in the y-direction. The blue arrows represent the components of the gravity present in each scenario.

g∥y

= g sinΘ° | (2)

Equation 2. Parallel Gravitational Component

Where:
g∥y
= gravitational component parallel to the plane g = Earth’s gravity (9.81 m
s

2

)
Θ° = angle between the inclined plane and the base
g⊥z = g cosΘ° | (3)

Equation 3. Perpendicular Gravitational Component (Tangential Gravity)

Where:
g⊥z
= gravitational component perpendicular to the plane g = Earth’s gravity (9.81 m
s

2

)
Θ° = angle between the inclined plane and the base

Since the bioreactor remains stable along the y-axis, meaning it does not slide on the inclined plane,
g∥y
is the effective gravitational force due to this stability, seen in Eq. 4. This is because the centripetal

acceleration lies in the yz-plane, meaning the bioreactor rotates around the y-axis. Regarding, it is aligned with the axis of centripetal acceleration, making g⊥z
the gravitational component that balances the rotational acceleration. Centripetal acceleration will be used instead of centrifugal acceleration because the particle's position is ideal in the middle of the bioreactor (not near its circumference). Solving Eq. 2 for in terms of Θ, Eq. 5 shows the angle of the inclined plane that produces the effective gravitational force.

gtar = g∥y
gtar = g sinΘ° | (4)

Equation 4. Targeted Gravity Case 1

Where:
gtar = intended partial gravity

g∥y
= gravitational component parallel to the plane g = Earth’s gravity (9.81 m
s

2

)
Θ° = angle between the inclined plane and the base

Θ = sin⁻¹
(

g∥y

g

) | (5)

Equation 5. Inclined Plane Angle

Where:
gtar = intended partial gravity

g∥y
= gravitational component parallel to the plane g = Earth’s gravity (9.81 m
s

2

)
Θ° = angle between the inclined plane and the base

Although the inclination angle equation establishes the environment in which the particle experiences modified gravitational forces, the particles should be in a state of "free fall” at any inclination position. Therefore, calculating the centripetal acceleration is necessary.

### Centripetal Acceleration

Given that uniform, steady circular motion is required for laminar flow, centripetal acceleration will be used. The centripetal acceleration (ac
) is directed towards the center, with the sole opposing acceleration being g⊥z
. Therefore, the accelerations should be counteracting to ensure that no net force is exerted on the particle, as demonstrated in Eq. 6, with Eq. 3 and the substitution of the relevant quantities for ac .

ac = g⊥z ⟹
ω
2R = g cosΘ° | (6)

Equation 6. Net Horizontal Acceleration

Where:
ac = centripetal acceleration

g⊥z
= gravitational component perpendicular to the plane ω = angular velocity
g = Earth’s gravity (9.81 m
s

2

)
Θ° = angle between the inclined plane and the base R = radius of rotation of the particle to the center

The preceding steps are predicated on the initial assumption that the component of gravity parallel to the plane constitutes the target of partial gravity, as seen in Eq. 4, with the perpendicular component aligned along the same axis as the centripetal acceleration, thereby facilitating cancellation. Nonetheless, during circular motion, the particle does not remain fixed at a single position; instead, it encounters varying net accelerations at different locations. Consequently, two additional positions are calculated to determine the necessary RPM range. Previously, it was assumed that the particle was moving only along one axis, as illustrated in Figure 16. For the positions of interest, it assumes that all accelerations acting on the particle will partially cancel each other out until the desired net acceleration is achieved. This total acceleration is denoted as gtar, where it stands for the intended partial gravity.

Eq. 7 shows the total gravity calculated from the free-body diagrams when the particle is at the top and the bottom.
gtar = √(ω²R ± g⊥z
)

2 + g∥y

2 | (7)

Equation 7. Targeted Gravity in Top and Bottom Placement

Where:
ω | = angular velocity
R | = radius of bioreactor
gtar = intended partial gravity
g∥y | = gravitational component parallel to the plane
g⊥z | = gravitational component perpendicular to the plane

As for the sides, the particle will have the equation shown in Eq. 8.

gtar = √(ω²R)
2 + g⊥z

2 + g∥y
2 | (8)

Equation 8. Targeted Gravity in Sides Placement

Where:
ω | = angular velocity
R | = radius of bioreactor
gtar = intended partial gravity
g∥y | = gravitational component parallel to the plane
g⊥z | = gravitational component perpendicular to the plane

Being less detailed on the vector location and using the cosine rule, the intended partial gravity can also be calculated as seen in Eq. 9. However, in this equation, the angling of the plane does not have an effect.

gtar = √(ω²R)
2 + g² + 2 ∗ g ∗ ω²R ∗ cosα° | (9)

Equation 9. Targeted Gravity in Overall Placement

Where:
ω | = angular velocity
R | = radius of bioreactor
gtar = intended partial gravity g = Earth’s gravity (9.81 m
s

2

)
α = angle between the gravity vector and the centripetal acceleration vector

Using Eq. 6 and solving for the centripetal acceleration in Eqs . 6, 7, 8, and 9, the centripetal acceleration at different positions of the system is given in Eq. 10.

ac = g cosΘ°

ac = √gtar
2 − g∥y

2 ± g⊥z

ac = √gtar
2 − g∥y

2 − g⊥z

2

ac = −g ∗ cos α° ± √gtar
2 − g² ∗ sin² α° | (10)

Equation 10. Centripetal Acceleration

Where:
ac | = centripetal acceleration
g | = Earth’s gravity (9.81 m
s

2

)
Θ° = angle between the inclined plane and the base gtar = intended partial gravity

g∥y
= gravitational component parallel to the plane

g⊥z
= gravitational component perpendicular to the plane
α = angle between the gravity vector and the centripetal acceleration vector

Following the establishment of the connection for ac

, ω can be subsequently calculated.

### Angular Velocity

After manipulating Eq. 6, Eq. 11 was used to isolate the angular velocity.

ω = √
ac
R

(11)

Equation 11. Angular Velocity

Where:
ω = angular velocity
ac = centripetal acceleration
R = radius of rotation of the particle to the center

### RPM

Utilizing Eq. 12, the relationship between RPM and angular velocity is demonstrated [86].

RPM =

60ω
2π

(12)

Equation 12. RPM

Where:
RPM = revolutions per minute
ω = angular velocity

Substituting Eq. 11 into Eq. 12, Eq. 13 shows the RPM for the bioreactor.

RPM =

60
2π

√
ac
R

(13)

Equation 13. Bioreactor RPM

Where:
RPM = revolutions per minute
ac = centripetal acceleration
R = radius of rotation of the particle to the center

The bioreactor's rotation could subsequently be calculated. However, one of the limiting factors in its rotation is the linear velocity induced by the fluid's tangential motion. Therefore, it is necessary to determine the system's linear velocity.

### Linear Velocity

The fluid within the bioreactor exhibits tangential movement concurrent with rotation. Eq. 14 illustrates the relationship between angular velocity and linear velocity [86].

v = ωR | (14)

Equation 14. Linear Velocity in Terms of Angular Velocity

Where:
ω = angular velocity
v = linear velocity
R = radius of rotation of the particle to the center

By substituting Eq. 11 into Eq. 3, Eq. 15 illustrates the linear velocity of the bioreactor.

v⊥ = √R ∗ ac
(15)

Equation 15. Tangential Velocity

Where:
v⊥ = tangential velocity
ac = centripetal acceleration
R = radius of rotation of the particle to the center

Given that the fluid possesses a tangential velocity, the particles suspended within it exhibit a sedimentation velocity. To facilitate “free-fall" conditions for the particles, the sedimentation velocity must be computed.

### Sedimentation Velocity

Sedimentation velocity refers to the terminal velocity of a particle within a quiescent fluid [87]. At this velocity, the particle experiences no acceleration because its terminal velocity remains constant. Utilizing Stokes’s law, the upward drag force resisting the particle's descent must be equal to the downward gravitational force [88]. However, Stokes’s law is predicated upon three fundamental assumptions:

1) The particle is small and spherical.
2) The particle does not rotate within the fluid.
3) Reynold’s number is considerably less than 1.

Although cells are not perfectly spherical, Stokes’ law provides an approximate estimation of the terminal velocity. For simplification purposes, the extraction of the equation would be visualized in a 2D system. Referring to Figure 17, the particle is suspended within the fluid; therefore, the net force exerted on the particle can be calculated as shown in Eq. 16.

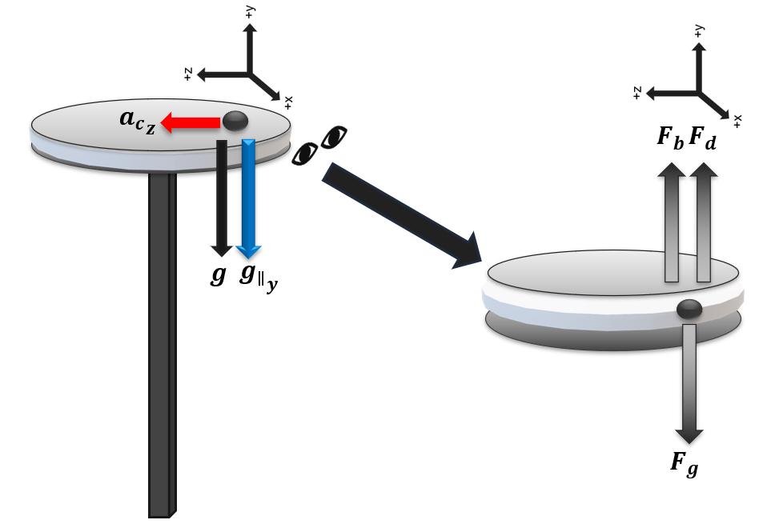
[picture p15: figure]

Figure 17. Free Body Diagram of the Particle in Fluid
The figure illustrates the forces acting upon the particle during its suspension within the fluid.
Fg = Fb + Fd | (16)

Equation 16. Net Driving Force on the Particle

Where:
Fg = gravitational force exerted on the particle (the gravitational component that causes the fall) Fb = buoyancy force exerted on the particle
Fd = drag force exerted on the particle

Eq. 17 and Eq. 18 show the equivalence of the gravitational force (Fg) in a fluid and the buoyancy force (Fb), respectively [88].

Fg = V ∗ ρp ∗ gtar | (17)

Equation 17: Equivalence of Gravitational Force

Where:
Fg | = gravitational force exerted on the particle
V | = volume of the particle
ρp | = density of the particle
gtar = intended partial gravity

Fb = V ∗ ρf ∗ gtar | (18)

Equation 18: Equivalence of Buoyancy Force

Where:
Fg | = gravitational force exerted on the particle
V | = volume of the particle
ρf | = density of the fluid
gtar = intended partial gravity

Assuming that the particle’s shape is spherical, the volume of the sphere is determined as shown in Eq. 19.

Vs =

4
3

πr

3
(19)

Equation 19: Volume of Sphere

Where:
Vs
= volume of the sphere
r = radius of the sphere

The drag force under consideration is that exerted on a spherical particle, as demonstrated in Eq. 20 [88].

Fd = 6πrηfvt
(20)

Equation 20: Drag Force

Where:
Fd = drag force exerted on the particle r = radius of the particle
ηf = fluid viscosity
vt = sedimentation velocity

Utilizing Eqs. 17-20, Eq. 21 is derived as the fully substituted form of Eq. 16.

Fg = Fb + Fd ⟹
Vs ∗ ρp ∗ gtar = Vs ∗ ρf ∗ gtar + 6πrηfvt ⟹

4
3

πr

3
∗ ρp ∗ gtar =

4
3

πr

3
∗ ρf ∗ gtar + 6πrηfvt
(21)

Equation 21: Fully Derived Net Driving Force on the Particle

Where:
r | = radius of the particle
ρp | = density of the particle
ρf | = density of the fluid
gtar = intended partial gravity
ηf | = fluid viscosity
vt | = sedimentation velocity

The sedimentation velocity equation, as seen in Eq. 22, is derived from Eq. 21 [88].

vt =

2
9∗ηf

(ρp − ρf) ∗ r

2
∗ gtar | (22)

Equation 22: Sedimentation Velocity

Where:
vt = sedimentation velocity
r = radius of the particle ρp = density of the particle gtar = intended partial gravity
ρf | = density of the fluid
ηf | = fluid viscosity

Nevertheless, the values derived from the settling velocity are predicated upon various assumptions. To confirm that the particle remains in laminar flow, thereby validating the preceding calculations of sedimentation velocity, the Reynolds number (Rep) should be computed [88]. The particle Reynolds number should be less than 2,000 to maintain laminar flow. If it exceeds 3,500, the flow becomes turbulent; for values in between, the flow is transitional [89]. By utilizing Eq. 23, these calculations can be confirmed [90].

Rep =

ρf∗(vp+vf)∗2∗r
ηf
< 2,000 | (23)

Equation 23. Particle Reynolds Number

Where:
Rep = particle Reynolds number
ρf | = density of the fluid
vf | = velocity of the fluid
vp | = velocity of the particle
r | = radius of the particle
ηf = fluid viscosity

Given the presence of motion, shear stress influences both the particle and the fluid. Shear stress is defined as the deformation of an object due to the application of a tangential force on its surface [91]. The maximum shear stress on the particle occurs at the circumference, as indicated by Eq. 24, which demonstrates the maximum shear stress on the particle [90].

τmax = μ

vt∗3
2∗r

(24)

Equation 24. Particle Shear Stress

Where
vt = sedimentation velocity τmax = maximum shear stress
μ | = fluidic dynamic viscosity
r | = radius of the particle

Regarding the fluid shear stress, it originates from laminar flow, resulting in varying fluid velocities at different levels [92]. Shear stress within the fluid can influence cellular integrity to such an extent that it may induce cell death [92]. Eq. 25 delineates the shear stress exerted by a Newtonian fluid on a surface [93]. This equation may be applicable in modeling the interaction between bubbles and particles [64].

τ = μ

∂υ
∂r | (25)

Equation 25. Fluid Shear Stress

Where
τ = fluid shear stress
μ = fluidic dynamic viscosity
∂υ
∂r = gradient of the fluidic velocity (shear rate)

Given that the fluid undergoes continuous rotation, the velocity gradient can be approximated by the system's tangential velocity. Furthermore, since the initial simulation and calculations primarily focus on the maximum shear in all cases, the change in radius would not occur, implying that the radius remains the same. Accordingly, Eq. 25 can be expressed as shown in Eq. 26.

τ = μ ∗ ωR | (26)

Equation 26. Fluid Shear Stress

Where
τ = fluid shear stress
μ = fluidic dynamic viscosity
ω = angular velocity
R = radius of rotation of the particle to the center

With further comprehensive research, the shear stress could achieve higher accuracy. However, several experimental tests were conducted using a cylinder instead of a disc to measure the wall shear stress of specific fluids. Since there are no numerical values, the shear stress would be calculated using an expected RPM and adjusted until the acceptable shear stress is calculated.

### Dynamic Portion

To improve the mathematical model and obtain more precise RPM values, certain factors influenced by rotational effects must be considered. Cells undergo continuous growth during culture, which affects the number of particles in the bioreactor. Consequently, the progression of cell growth over time is a critical factor. Although various models describe cell growth, the exponential growth model will be employed to simulate the most extreme scenario, as defined by Eq. 27 [94].

N(t) = Noe

rt
(27)

Equation 27. Particle Growth Over Time

Where:
N(t) = particle concentration over time
No | = initial particle concentration
t | = time (in hours)
r | = population growth rate

Since particles act as barriers within fluids, increasing particle concentration increases viscosity [95]. Using the model developed by Krieger and Dougherty, this impact on viscosity can be quantified. Eq. 28 shows the relevant equation for both low and high shear rates [95]. Assuming the particles are spherical, the maximum packing density is approximately 0.648, and the intrinsic viscosity is 2.5 [95].

ηf,n = ηf(1 −

φ

φmax

)

−[η]∗φmax | (28)

Equation 28. Viscosity Change

Where:
ηf,n = altered fluid viscosity
ηf | = fluid viscosity initial (before adding particles)
φ | = solid fraction in suspension
φmax = maximum solid fraction in the suspension
[η] = intrinsic viscosity that is dependent on particle shape

As the particle concentration increases, the solid fraction in suspension (φ) will change over time. Eq. 29 illustrates the variation of the solid fraction [95].

φ(t) =

N(t)∗Vp
Vf

(29)

Equation 29. Dynamic Solid Fraction in Suspension

Where:
φ(t) = solid fraction in suspension (dynamic)
N(t) = particle concentration over time
Vp | = volume of one particle
Vf | = volume of fluid

The viscosity change would then be dynamic, as seen in Eq. 30.

ηf,n(t) = ηf(1 −

φ(t)

φmax

)

−[η]∗φmax | (30)

Equation 30. Dynamic Viscosity Change

Where:
ηf,n = altered fluid viscosity
ηf = fluid viscosity initial (before adding particles)
φ(t) = solid fraction in suspension (dynamic)
φmax = maximum solid fraction in the suspension
[η] = intrinsic viscosity that is dependent on particle shape

Eq. 26 accounts for fluid shear stress and dynamic viscosity. As shown in Eqs. 29 and 30, changes in particle concentration result in variations in fluid viscosity. Additionally, to maintain the system's integrity and prevent particle failure or death, the rotational velocity must be adjusted appropriately. Therefore, using Eqs. 26 and 30, Equation 31 depicts the dynamic fluid shear stress.

τ(t) = ηf,n(t) ∗ ω(t)R | (31)

Equation 31. Dynamic Fluid Shear Stress

Where
τ(t) = fluid shear stress (dynamic)
ηf,n(t) = altered fluid viscosity (dynamic)
ω(t) = angular velocity (dynamic)
R = radius of rotation of the particle to the center

As particle properties change over time, the RPM needs to be adjusted to counteract the relevant gravity component. However, the current mathematical model lacks sufficient detail for precise accuracy, leading to an overestimation of RPM. Therefore, the RPM would be selected and fine-tuned based on particle property limits, such as maximum shear stress.

## 4.3 Numerical Sampling

As mentioned in the Calculations - Centripetal Acceleration Section, three methods were used to calculate the RPM and the angle required to achieve the desired gravity. From the calculations, some imaginary values appeared in certain portions, indicating that it would not be realistic to achieve the intended gravity at this location. Additionally, due to vector balancing, some positions resulted in high RPM values. However, to ensure that the particles (specifically the cells) are not harmed by rotationinduced motion, we will use the average RPM and angle for each intended gravity, as shown in Table 5.

Table 5. Numerical Values of Initial RPM and Angle Values

Gravity (m ) s 2 | Inclined Angle (°) | RPM (rev min)
1G | 90° | 0
3 G 8 | 16° | 10
1 G 6 | 13° | 16
µG | 0° | 23
The table presents some of the final numerical values derived from the equations detailed in the Calculation section. The table includes four different gravity values and their respective incline angles, along with the RPM for a specific bioreactor radius of 0.025m.

### Correlation and Analysis

After calculating both the sedimentation velocity and the tangential velocity, the ratio of these velocities provides valuable insights into particle interactions within the fluid. If the sedimentation velocity exceeds the tangential velocity, the particles will settle, which is undesirable. Conversely, if the terminal velocity is lower than the tangential velocity, the particles remain in suspension continuously. The objective is to ensure that the tangential velocity exceeds the terminal velocity. The correlation is

vt >≈ v⊥

If this condition is not satisfied, adjustments to the system should be implemented, such as increasing or decreasing the RPM.

Figure 18 illustrates the correlation between the RPM and the radius. The correlation is

RPM ∝

1
√R

, considering the centripetal acceleration is kept constant. Therefore, as the radius increases, the RPM decreases.

Figure 18. RPM vs Radius

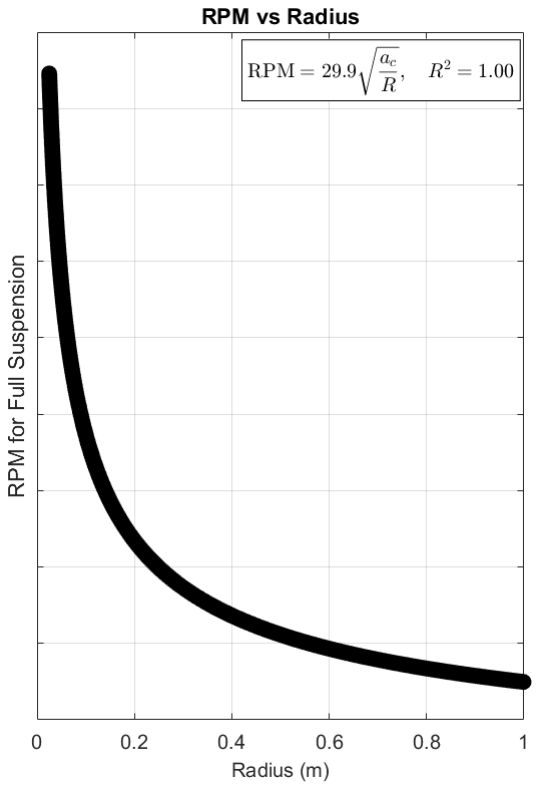
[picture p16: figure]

The figure illustrates that increasing the bioreactor radius decreases RPM.

## 4.4 Simulation

Given the presence of a few mathematical equations, a simulation can be conducted.

### Mathematical Simulation

The mathematical simulation relies on the equations presented in the Calculation section. Since there are many mathematical variables to add to make particle simulations truly accurate, the program was designed to allow easy data addition.

First, the program was done in Python, and four different Python files were created. The files included the following: generalized bioreactor, particle properties, particles in the bioreactor, and the application. The generalized bioreactor file contains functions that either find RPM and tilt from the intended gravity or, conversely, find the gravity from RPM and tilt. The particle properties (as stated in the Calculations section) are added to their own functions, each with its own variables, including the dynamic portion. Since the particles will be rotating inside the bioreactor, the ratio of sedimentation velocity to linear velocity is calculated to ensure that particles do not settle and that the shear stress remains within the acceptable range. Additionally, a heatmap showing gravity at each position in the bioreactor is shown, for both perpendicular and parallel gravity. Finally, the application file calls all the functions from the previous files to have an interactive website.

In the application, there are two tabs: simulation and math. The math tab explains the mathematical methods used in this paper and provides a quick summary of the application’s mathematical methods. The simulation portion contains the generalized and particle gravities. With that, the application is generated.

The heatmaps show how gravity is felt inside the bioreactor. In Figure 19, the parallel gravity in two different gravity environments (Earth and Mars) is shown. Looking at Earth’s gravity, there is a slight color gradient, showing that the gravity is not significantly different from one position to another. However, looking at Mars' gravity, the color gradient varies with the particle's position. As seen in Figure 19B, the bottom area has the lowest gravity, while the top area has the most extreme gravity. The sides have the middle (most accurately intended gravity). This is due to the correlation between RPM and radius, as seen in Figure 13.

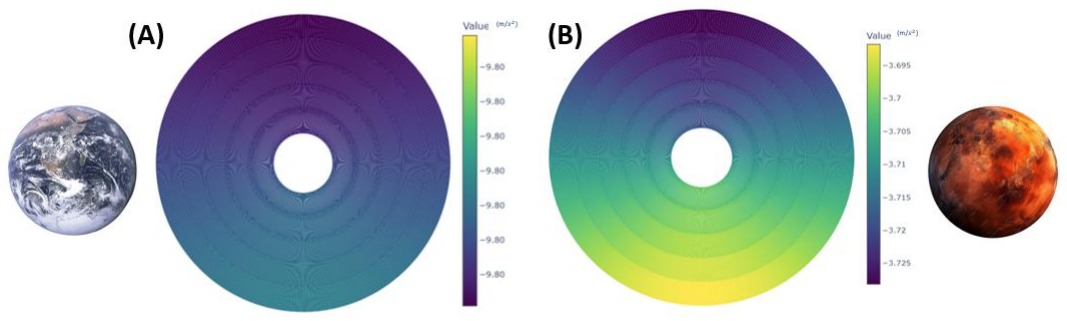
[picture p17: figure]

Figure 19: Parallel Gravity Component for Earth and Mars
The figure shows the effective gravity of (A) Earth and (B) Mars inside the bioreactor.

# 5.Components

After understanding the system's basic operation, choosing the right components is essential.

## 5.1 Motor, Driver, and Microcontroller

Given that a maximum of 1300 rpm is considered extreme when sustained for more than 10 minutes, as exceeding this limit can result in cell denaturation, a smaller radius is preferable to maintain healthy cell cultures [96]. Regarding view clearance, a significant aspect of the prototype is the visual assessment of the particle under rotation and at different inclinations. Therefore, the chosen bioreactor should have a small radius and a large viewing area.

To determine the torque required to continuously rotate the bioreactor, the moment of inertia and the angular acceleration must be calculated. However, since the bioreactor is expected to rotate from 0 rpm to a maximum of 50 rpm, the angular acceleration can be observed as the intended rpm increases over time. Since RPM provides more information than angular velocity, the torque can be found as seen in Eq. 32 [97].

τ = I ∗∝ ⟹ | (32)
τ = I ∗

∆ω
t

⟹

τ = I ∗

2π
60

∗RPM

t
Equation 32. Torque

Where:
τ = torque
∝ = angular acceleration
ω = angular velocity
RPM = revolution per minute
t = time it takes to change angular velocity

Focusing on the moment of inertia, the bioreactor is a cylinder with some extrusions. Assuming that the bioreactor is a cylinder, the moment of inertia is in Eq. 33 [98].

I =

m∗ r

2
2 | (33)

Equation 33. Moment of Inertia

Where:
m = mass of the rotating object r = radius of the rotating object

I = moment of inertia

Eq. 33 is the inertia of the rotation along the length of the cylinder, which applies to both the bioreactor and the rod. For the bioreactor, the radius would be the 50mL HARV to achieve the most extreme moment of inertia possible for the prototype. A diameter of 99.06mm, corresponding to a radius of 0.04953m, will be used. As for the mass, it was documented from the prior team that the empty mass of the bioreactor is .03kg, and using the volume of 50mL, the density of the water 1,000 kg
m³

, and the prior knowledge of 1mL = 10⁻⁶m³
the mass of the filled bioreactor can be measured using Eq. 34 [99].
m = ρ ∗ V | (34)

Equation 34. Mass

Where:
m = mass of the system
V = volume of the system
ρ = density of the system

Adding the mass of the bioreactor to the mass of the system inside it, the mass of the filled bioreactor is 0.08kg. However, since the actual mass of the total bioreactor is never precisely known, a safety factor of 1.5 is used. For that, the mass of the filled bioreactor is 0.12kg. Plugging the filled mass of the bioreactor and the radius of 0.04953m in Eq. 33, the moment of inertia is 1.47 × 10⁻⁴kgm²
. If it takes 1 second to
go from 0 RPM to a maximum RPM of 50 RPM, plugging the values into Eq. 32 will provide a torque of 2.57 × 10⁻⁵

rev
s

2

, which is 1.61 × 10⁻⁴Nm.

Since the torque is very low, most motors would be suitable for the prototype. However, the accuracy of motor rotation at 20-50rpm is essential. Therefore, the best way to achieve that is to break down the steps per motor revolution. The NEMA 17 has a step angle of 1.8°, requiring 200 steps to complete one full turn [100]. It draws up a current phase of 1.6A, and the digital stepper driver used has a current per phase of 0.3-2.2A [100], [101]. Since the current per phase of the motor is within the driver's range, the driver would be applicable. It reaches a maximum temperature of 50 °C, exceeding the incubator’s temperature limit. Furthermore, the maximum step resolution is 1/100, allowing the driver to divide a complete step into 100 smaller steps. This enhances the variation in angle increments in the prototype, thereby enabling a broader range of inclination solutions. Using Eq. 35, the number of steps per revolution is 20,000.

### Total Microsteps =

360∗(Step Resolution)

−1

Full Step Angle

(35)

Equation 35. Microsteps

Regarding the inclination plane rotation, the most critical aspect is to ensure that, during the plane's stationary motion, the motor remains stationary. For that, Eq. 36 would be used to calculate the holding torque.

τ = m ∗ g ∗ d | (36)

Equation 36. Torque

Where:
τ = torque
m = mass
d = perpendicular distance from the pivot

The mass acting during the motor's rotation would be divided into two main components: the acrylic inclined plane and the bioreactor with its motor. The acrylic plane has a length of 0.127m, a width of 0.1524 m, a thickness of 0.00635m, and a density of 1190 kg
m³

, the distance from the pivot point is 0.0635m. As for

the bioreactor and motor, their total mass is the sum of 0.08kg and 0.28kg, with 0.0508m from the pivot. Additionally, to ensure safety, a safety factor of 2 would be used. For this, the holding torque is calculated to be 0.542 Nm. Since the camera component was not taken into consideration due to the unknown mass, the acceptable holding torque would be about 0.55-0.6 Nm.

The Nema 23 173.5 in-oz has a maximum holding torque of 1.225 Nm [102]. Since the holding torque exceeds the maximum opposing torque, the motor is suitable. The maximum temperature reaches 266 °F (130 °C), exceeding the incubator's temperature limit [102]. Additionally, the motor has a current rate per phase of 2.8A and has a step angle of 1.8° [102]. Since this component is a stepper motor, a stepper driver has been selected to enable more precise rotational movement. The digital stepper driver used has a current per phase of 2.35-8A [103]. Since the current per phase of the motor is within the driver's range, the driver would be applicable. It has a maximum temperature of 85 °C, exceeding the incubator’s temperature [103]. Furthermore, the maximum step resolution is one hundredth, allowing the driver to divide a complete step into 100 smaller steps [103]. This enhances the variation in angle increments in the prototype, thereby enabling a broader range of inclination solutions.

The microcontroller employed for direct motor control is the Arduino GIGA R1 WiFi, which incorporates a dual-core that can be programmed separately [104]. A key feature of this Arduino is its capability to connect to Wi-Fi [104]. Additionally, it has Bluetooth connectivity capabilities [104]. Finally, since there are a lot of pins needed for this project, the Arduino comes with 76 GPIOs and several communication buses [104].

## 5.2 Base Material

Acrylic sheets must be utilized as the foundational material for the prototype [105]. Given that the prototype will be positioned within the incubator and tests are anticipated to be conducted therein, the incubator's humidity and temperature are likely to influence the base material of the prototype.

The physical properties of the acrylic sheets, as determined by the ASTM method D648, show that a thickness of 0.236mm has a deflection temperature under a load of 264 psi of 99 °C, and the forming temperature ranges from 170 to 190 °C [105]. The softening point, as determined by the ASTM method D1525, is 115 °C, with a maximum recommended continuous service temperature of 82 °C [105]. Since the incubator would have a temperature significantly lower than the temperatures stated above, the minimum width of the acrylic sheets would be 0.236mm.

Additionally, the acrylic exhibits good insulating properties, with a surface resistivity higher than that of most plastics, making it a viable protector of the electrical components in the prototype. Due to humidity exposure, the acrylic is expected to expand by 0.6%, 0.4%, and 0.2% at humidities of 100%, 80%, and 60%, respectively [105].

Additionally, we need to ensure that the prototype will not degrade in the presence of chemical additives. Another limitation is the use of isopropyl alcohol (the most used alcohol in labs). Acrylic has limited resistance to this chemical [105]. Therefore, it is advisable to avoid using alcohol on the surface or placing the prototype on a surface with alcohol to ensure longevity. However, since there is limited resistance, it will be stated that limiting the use of alcohol is a must.

## 5.3 Rod

To achieve the inclination angles, the plane must undergo rotation. This rotation is facilitated by connecting the inclined plane to a rod that transfers linear motion into rotational motion. The choice of material for the rod is critical to the prototype's viability and safety. Accordingly, aluminum is selected as the material for the rod.

A primary characteristic of aluminum is its combination of lightness and strength [106]. Given that the inclined plane, in conjunction with the NEMA 17 and the bioreactor, contributes to the overall weight the rod must support, aluminum is the most suitable material. As the rod will be supported at its end, it is advantageous that the material's weight does not augment the stresses at these points.

Additionally, aluminum has a melting point of 660°C, which is higher than the incubator temperature, ensuring its stability [106]. Regarding the incubator, aluminum is non-corrosive due to its protective oxide layer; however, it can corrode if exposed to highly alkaline or acidic environments for extended periods [106]. Therefore, it is advisable to be cautious and avoid direct contact between aluminum and acidic or alkaline chemicals [119]. As a safety feature, aluminum is ductile and malleable [106]. In the event of failure, aluminum absorbs significant energy before breaking and deforms before failure [106]. This property provides a visual warning that the prototype may fail before it does.

## 5.4 Bioreactor

For the bioreactor, the part was recreated to accommodate the new materials available on the market. Using the provided CAD, the layers could be generated [64]. The structural layers of the bioreactor are as follows: top plate, bubble plate, gasket, spatial area, gas membrane, and bottom plate [64]. Since each layer is separated, all the layers have cut-out holes around their circumference. The layers are then stacked and bolted together, as shown in Figure 20.

Figure 20: HARV Layers

# 6.Prototype

## 6.1 Wiring

After discussing the components of the prototype, various electrical components will require connections. Initially, it is essential to possess two motors and two stepper motor drivers. The rationale for this requirement is that one motor will be connected to the bioreactor to facilitate its rotation, and the other motor will be attached to the rod that rotates the plane. Considering that the motors used have high torque, it is impractical to connect both to a single driver. Connecting them to a single driver would result in current division between the two motors. Since these motors demand more than three-fourths of the available current, such a setup would increase hazards and compromise system safety. Although procuring two drivers incurs higher costs, electrical safety remains a primary design consideration. Additionally, this would allow the wiring to be neat and aligned with the prototype’s needs.

The motors have four wires, which should be connected to the corresponding terminals on the stepper motor driver: A-, A+, B-, and B+. The stepper driver is interfaced with the Arduino via the following connections: STEPS+, DIRECTION+, ENABLE+, and GND. The STEP+ connection controls the number of steps, thereby controlling the shaft's rotation. The DIRECTION+ connection determines the rotation direction. The ENABLE+ connection specifies whether the rotational system will be operated manually or exclusively by the driver.

The negatives of STEP, DIRECTION, and ENABLE shall be connected to GND. While this is not obligatory, ensuring they remain disabled would enhance safety. Regarding GND, the entire system must be referenced to a common ground to ensure safety and comply with wiring standards.

Given that emergency safety is a critical requirement for the prototype, activating the stop button must halt all system motion. Accordingly, the VCD of the drivers is linked to one terminal of the stop button, while the opposite terminal is connected to the power source (power plug). The Arduino is powered independently via a battery, ensuring a dedicated power supply. Nevertheless, the battery grounds the Arduino, which is also connected to the drivers' GND, thereby ensuring uniform grounding across all components. Using KiCad, Figure 21 illustrates the electrical connections displayed in the schematic.

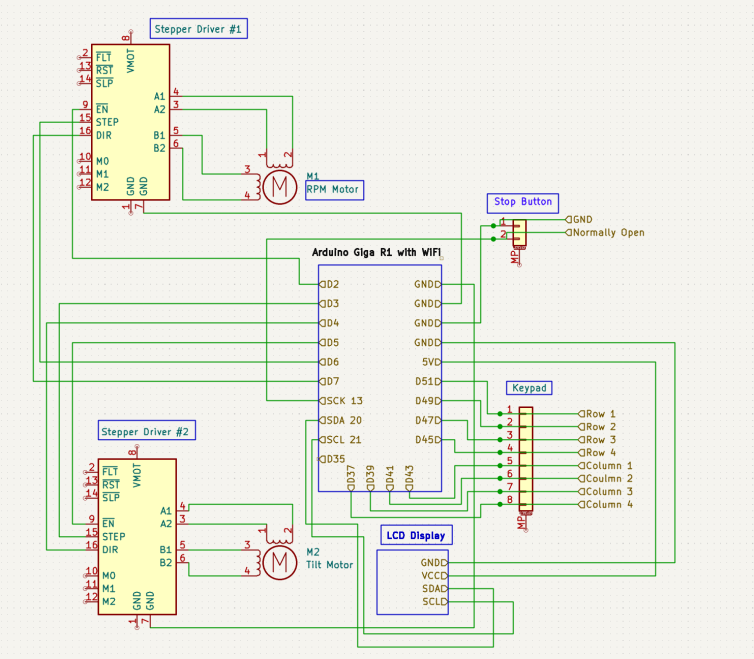
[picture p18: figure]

Figure 21: Electrical Schematic

## 6.2 Overall Prototype Basics

With the components assembled and the electrical connections established, the prototype could then be constructed.

Constrained by the dimensions of the incubator, the prototype should not exceed the specified limits of the incubator: 23 × 17 × 14 in. As Figure 22 illustrates, the dimensions of the initial prototype estimate are significantly smaller than these constraints, with a value of 11.9 × 13.0 × 2.95 in. The dimensions could be reduced by cutting off the excess portion of the rod; even at this size, it still fits the incubator.

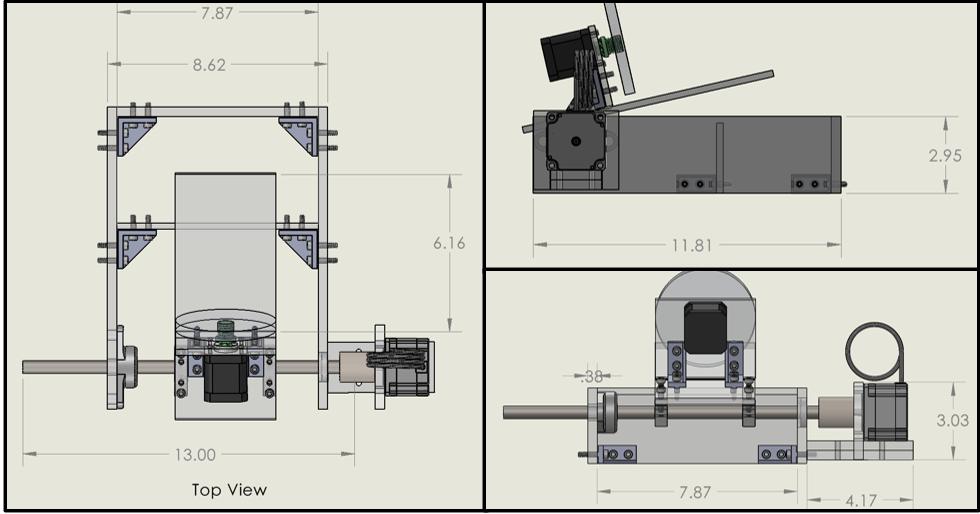
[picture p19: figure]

Figure 22. Prototype Dimensions (inches)

The prototype initially comprises a rectangular acrylic sheet base. An aluminum rod is positioned along two parallel sides of the base. The aluminum rod allows the inclined plane to rotate, as its movement requires a specific angle. The most straightforward and effective way to automatically facilitate this rotation is to use a rotatable rod.

To enable the rotation of the rod, it must be connected to a suitable motor capable of facilitating such motion. Accordingly, the rod is affixed to the NEMA 23 stepper motor. Since the rod's diameter is 0.5 in, it is connected to the motor shaft via a coupler. Nevertheless, it is imperative to secure the aluminum rod in position. To achieve this, bearings are installed at both ends of the rod.

A ball bearing is positioned at the end nearest the motor to facilitate smooth rotation and prevent increased stress on the motor shaft. The rod is subsequently connected to the inclined plane via two aluminum brackets. These brackets fit snugly into the rod through their circular holes and are fastened to the inclined plane at the horizontal section. The horizontal section attached to the inclined plane supports the bioreactor and the motor. The bioreactor is coupled to the motor using the motor coupler. The motor is secured in place by being screwed to the horizontal section.

The base is secured using L-shaped brackets to ensure stability. Furthermore, the inclined plane and the bioreactor plane are also supported by L-shaped brackets. The additional components in the prototype include a modification to the thickness of the front width of the base to ensure that the inclined plane does not topple from the initial angle. The detachable camera is positioned at the end of the inclined plane, seen in Figure 23. A safety wall is installed to prevent the inclined plane from exceeding 0 or 90 degrees, as seen in Figure 24. A box is made to ensure the electrical wiring, keypad, and emergency button are connected.

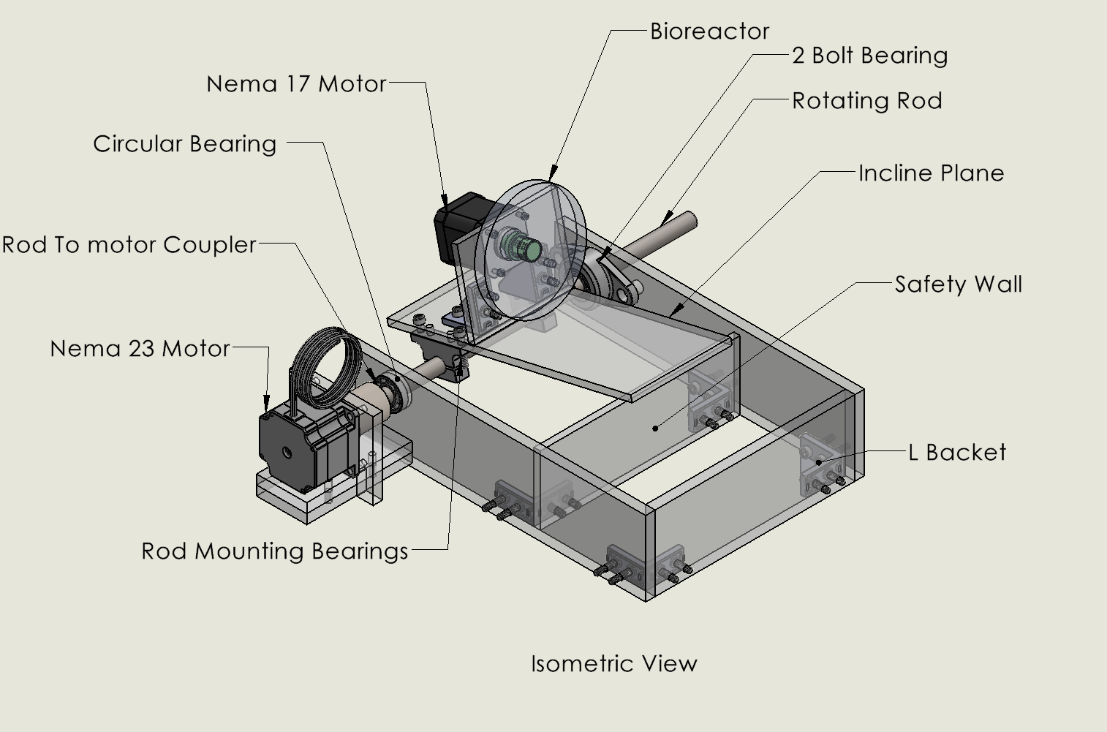
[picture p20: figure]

Figure 23. Isometric View of Prototype CAD

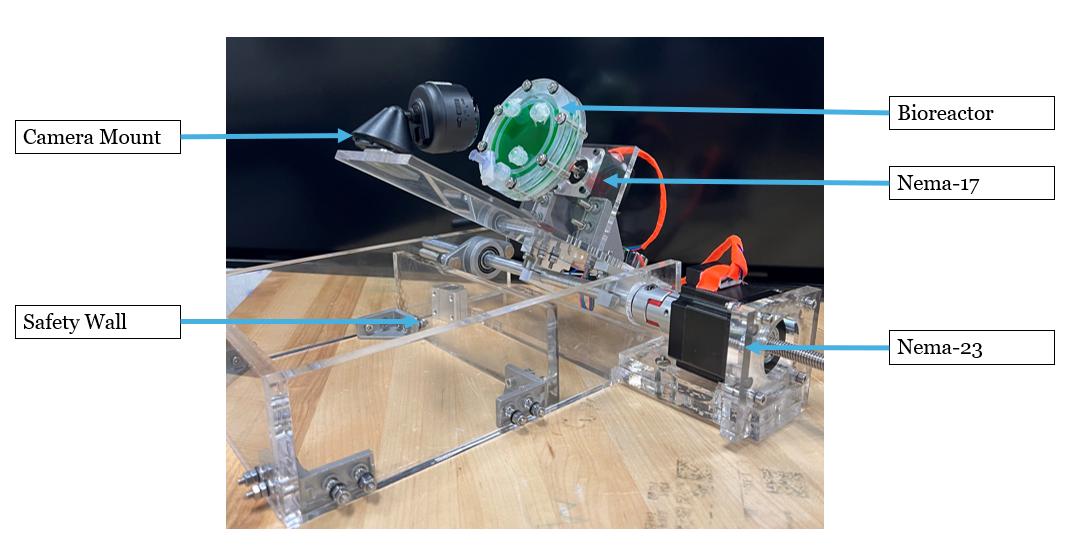
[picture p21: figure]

Figure 24: Prototype Angled View

# 7.Test Methods

To guarantee the validity of the results and decisions, specific tests must be conducted.

To validate the prototype, specific tests were conducted to quantify the effects of simulated gravity on the spacemen. Since gravity is only tested by its impact on a mass, there are two ways in which gravity’s effect is induced on the specimen in this prototype: RPM and inclination angle. Accordingly, the RPM Validation Test and the Inclination Angle Test were performed to assess these components.

The platform's tilt is a critical element in simulating partial gravity. The Inclination Angle Test was conducted to assess the accuracy of the tilt relative to the programmed angles. Images of the prototype were captured at eye level using a phone, with the platform tilted in 10° increments from 0° to 90°. Three images were taken at each step to assess stability. The angles in the image were measured three times in ImageJ to ensure accuracy. Statistical analysis, including the calculation of means and standard deviations, was performed in R. Finally, a linearity test was conducted to compare the measured angles with the expected angles.

To minimize shear on the specimen, the platform's rotational speed must remain constant. The RPM Validation Test was conducted to evaluate two criteria: the prototype’s ability to generate the intended gravitational effect and to maintain steady flow under partial gravity. A tachometer was used to measure rotational speeds ranging from 5 RPM to 60 RPM in 5 RPM increments. For each RPM setting, three measurements were recorded at 30-second intervals to evaluate stability over time. Statistical analysis, including mean and standard deviation calculations, was performed in R for each RPM condition. Finally, the linearity between the measured and target RPMs was assessed to verify the accuracy of the rotational control.

The Alginate Bead Flow Test was conducted to verify that the specimen follows a circulator trajectory under partial gravity and to provide visual confirmation of steady flow. Alginate beads, a type of natural polymer widely used in drug delivery and cell studies, were selected to “mimic” cells due to their controllable size and encapsulation properties [107]. The droplet size during formation determines the bead size, offering flexibility in producing “mimic cells” of varying dimensions. Beads were made using the extrusion dripping method [108]. Due to their dispersive properties, visualization was achieved using darkfield imaging. For the test, a replica of the Alginate Bead Fluid Dynamics Validation was run [64]. A oneminute video was recorded for each condition using a stabilized camera aligned parallel to the inclined plane. Videos were analyzed in MATLAB to extract particle motion and generate trajectory graphs.

To ensure cell viability in the bioreactor, all materials in contact with the cells must be biocompatible and free of cytotoxic compounds. Compliance with ISO 10993-5: Tests for In Vitro Cytotoxicity was maintained to verify that the materials did not induce cell deformation or lysis [109]. The Indirect Contact Test assessed cell viability resulting from material-medium interactions [110]. Although L929 cells are the standard for cytotoxicity evaluation, NIH/3T3 cells were used in this study due to material availability constraints [111].

For the Indirect Contact Test, NIH/3T3 cells were seeded in T25 flasks and cultured to approximately 70% confluency [110]. Cells were then plated in a 96-well plate at a density of 1.0 × 10⁵
cells per mL,
with 50 μL of DMEM/FBS medium added to each well, bringing the total volume to 100 μL [110]. Two material samples- Nylon 500 mesh and Tegaderm- were incubated for 24 hours with a surface area-tomedia ratio of 3mm²
/mL [112]. The medium in the wells was subsequently replaced with the materialconditioned medium. Each sample was tested in triplicate and analyzed in diluted (50%) concentrations. Negative controls consisted of cells cultured with standard DMEM/FBS, while positive controls received PEI treatment [110]. The plate was incubated for 24 hours, after which 10% v/v Presto-Blue reagent was added to the medium for 5–10 minutes. Fluorescence readings were used to quantify cell viability. Data analysis was performed in R, and normality and variance were assessed before a one-sided unpaired t-test (α = 0.01), with the null hypothesis that cell viability in contact with each material would be equal to or greater than the normal cell viability.

# 8.Results

## RPM and Tilt Validation Tests

Measurements across the targeted RPM settings showed that the system provides values identical to the programmed RPMs with minimal variability. For each target RPM, the percentage error of the technical replicates was less than 1.5%, indicating good repeatability of the measurement process, supported by the small error bars in Figure 25A.

Running the lm function in R to find the linearity of the data, the equation was the following:
y = 0.99x − 0.06
With a slope of 0.99, there is a 0.81% error from the ideal slope. With that, it confirms that the measured and intended RPMs are the same, demonstrating the accuracy of the device and code for RPM. The R-squared value of the fit is 0.999, indicating that a linear fit is the most appropriate model. However, the intercept value of 0.06 is slightly higher than expected. With a percentage error of 6.4%, the difference could be due to experimental/ sampling errors.

As for the tilt angles, the system showed that the measured values match the programmed values. With little to no variability, the errors bars (which are barely seen in Figure 25B) show little variability.

Running the lm function in R to find the linearity of the data, the equation was the following:
y = 1.03x − 0.4
With a slope of 1.03, there is a 3% error from the ideal slope. With that, it confirms that the measured and intended tilts are the same, demonstrating the accuracy of the device and code for tilt. The R-squared value of the fit is 0.999, indicating that a linear fit is the most appropriate model. However, the y-intercept value of 0.4 is slightly higher than expected.

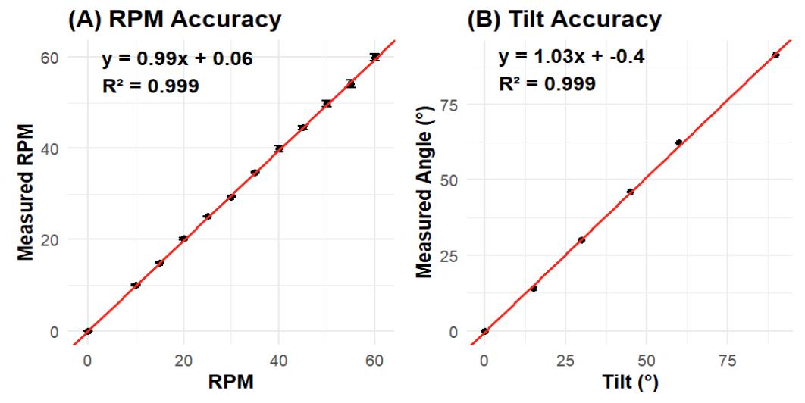
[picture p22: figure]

Figure 25. RPM and Tilt Validation
The figure shows the linear regression line. (A) The graph displays targeted RPM versus measured RPM.
(B) The graph shows the targeted tilt versus the measured tilt.

## Alginate Bead Test

For the alginate bead test, the goal is to observe a uniform circular flow. Using the recorded video and transferring it to MATLAB for analysis, the particle trajectories resemble those of the reference data (Dr. Phelan’s alginate bead fluid validation test), as shown in Figure 26 [64]. This confirmed a uniform circular trajectory.

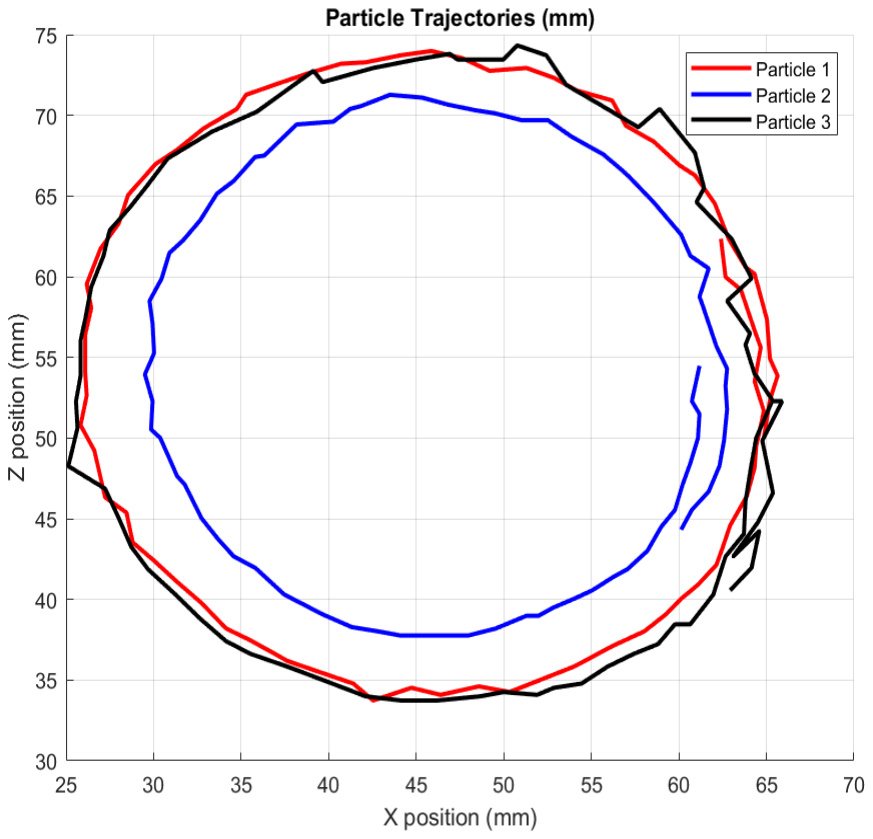
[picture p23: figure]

Figure 26. Alginate Bead Particle Motion
The figure shows the trajectory of the particles in one run of the bioreactor.

## Indirect Contact Test

Cell viability was assessed for two materials: Nylon 500 mesh and Tegaderm. Individual replicates for each condition are shown in Figure 27, with the mean value indicated below each group and the standard deviation represented.

For the Nylon 500 Mesh, the mean variability was 137.9%. Tegaderm had a mean viability of 95.1%. The results of the Levene Test (for variance) and the Shapiro-Wilk Test (for normality) indicated that all groups had normal distributions and equal variances.

Statistical analysis using a one-sided unpaired t-test revealed no significant differences in cell viability between the conditions and the healthy cell culture. Overall, all the materials exhibited high cell viability at a 50% dilution; Therefore, the null hypothesis has not been refuted, making the Tegaderm and Nylon 500 mesh acceptable material choices.

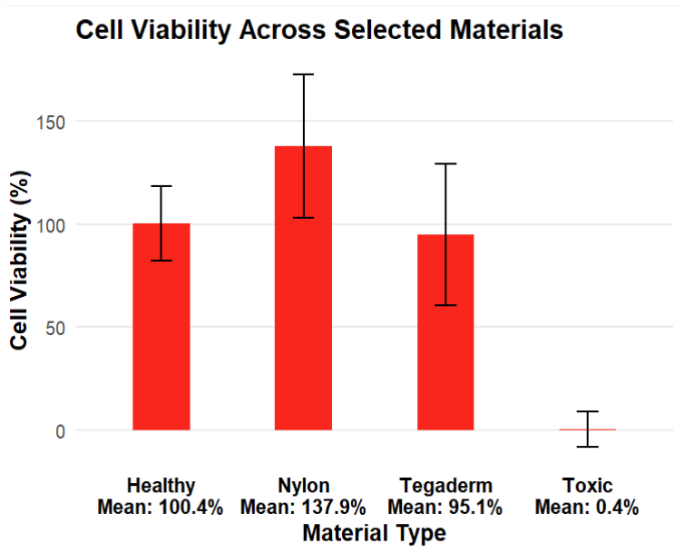
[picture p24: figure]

Figure 27. Cell Viability Per Material
The figure displays a scatter plot of cell viability across different conditions: healthy, toxic, nylon 500 mesh, and Tegaderm. The graph also shows the standard deviation for each group, along with its mean.

# 9.Cost

As for the cost, the prototype's per-unit cost would be roughly $615.00. This price is a rough estimation based on over-pricing and lowering the prices of different materials. The materials listed in Table 6 were discussed in the Components and Prototype sections.

Table 6: Material Cost

Material | Price
Arduino Giga R1 Wi-Fi | $48.72
Latching Emergency Stop Push Button Switch | $11.99
IPS Weld-On 3 Acrylic Plastic Cement | $26.99
Acrylic Sheet 3/8’’ Thick Cast | $49.99
Nylon Mesh 300 | $15.99
3M Tegaderm Roll | $25.81
Translucent Silicone Rubber 1/32’’ Thickness | $11.99
½’’ Diameter Aluminum Rod | $11.99
¼’’ Thick Clear Cast Acrylic | $9.99
Sun-Founder Elite Explorer Kit | $95.99
Luer Lock Tube Coupling ¼’’-28 | $9.26
Nema 23 Stepper Motor + Stepper Driver | $112.34
Nema 17 Stepper Motor + Stepper Driver | $45.99
Aluminum Easy-Access Base-Mounted Shaft Support (1/2') | $56.4
Mounted Ball Bearing | $25.14
Ball Bearing | $30.3
Motor Nema 23 to Shaft Coupler | $9.19
Motor Nema 17 to Shaft Coupler | $10.39

# 10. Summary and Conclusion

Overall, the prototype can simulate partial gravity using rotation and tilting. A created program enables a deeper understanding of particle and fluid properties, as well as gravity within the bioreactor. Looking at Table 7, all the criteria for the prototype were met except the computational model, which was a negotiable criterion. Therefore, it is reasonable to consider this prototype a success.

Table 7: Prototype Criteria
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

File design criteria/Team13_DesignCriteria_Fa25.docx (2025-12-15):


Temple University

# College of Engineering

# Bioengineering

Design Criteria

With Problem Statement Portion revised till Needs and Reference (1.4 not revised)

Partial Gravity Bioreactor

Presented By: Team #13

Dmitry M Hackel | Irene Bui
Jake Fisher | Zenub Abouzid

Supervised By:

Dr. Yah-el Har-el & Dr. Peter Lelkes

09 – 07 – 2025

Acknowledgment

We want to extend our most profound appreciation to the following individuals and organizations who have contributed to the completion of this project:
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

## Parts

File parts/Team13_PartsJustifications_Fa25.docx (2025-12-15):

Team 13: Partial Gravity Bioreactor Parts 10/10/2025

Parts Yet to Be Purchased (Now and Future):

1. Stepper Motor

To determine the torque required to rotate the bioreactor continuously, the moment of inertia and the angular acceleration must be calculated. However, since the bioreactor is expected to rotate from 0 rpm to a maximum of 50 rpm, the angular acceleration can be observed in terms of the intended rpm over time. Since RPM provides more information than angular velocity, the torque can be found as seen in Eq. 1.

τ=I*∝ ⟹ (1) τ=I*(∆ω)/t ⟹

τ=I*((2π)/60*RPM)/t

Where:

τ = torque

∝ = angular acceleration

ω= angular velocity

RPM = revolution per minute

t = time it takes to change angular velocity

Focusing on the moment of inertia, the bioreactor is a cylinder with some extrusions. Assuming that the bioreactor is a cylinder, the moment of inertia is in Eq. 2.

I=(m* r^2)/2 (2)

Where:

m = mass of the rotating object

r = radius of the rotating object

I = moment of inertia

Eq. 2 is the inertia of the rotation along the length of the cylinder, which applies to both the bioreactor and the rod. Focusing on the bioreactor, the radius of the bioreactor would be the 50mL HARV for the most extreme moment of inertia possible for the prototype. A diameter of 99.06mm, corresponding to a radius of 0.04953m, will be used. As for the mass, it was documented from the prior team that the empty mass of the bioreactor is .03kg, and using the volume of 50mL, the density of the water 1,000(kg)/(m^3) , and the prior knowledge of 1mL=10^(-6) m^3 the mass of the filled bioreactor can be measured using Eq. 3.

m=ρ*V (3)

Where:

m = mass of the system

V = volume of the system

ρ = density of the system

Adding the mass of the bioreactor to the mass of the system inside it, the mass of the filled bioreactor is 0.08kg. However, since the actual mass of the total bioreactor is never precisely known, a safety factor of 1.5 is used. For that, the mass of the filled bioreactor is 0.12kg. Plugging the filled mass of the bioreactor and the radius of 0.04953m in Eq. 2, the moment of inertia is 1.47×10^(-4) kgm^2 . If it takes 1 second to go from 0 RPM to a maximum RPM of 50 RPM, plugging the values into Eq. 1 will provide a torque of 2.57×10^(-5) (rev)/(s^2) , which is 1.61×10^(-4) Nm .

Since the torque is very low, most motors would be suitable for the prototype. However, the accuracy of the motor rotation at 20-50rpm is a must. Therefore, the best way to achieve that is by breaking down the steps per revolution taken by the motor. Most motors have a step angle of 1.8°, which requires 200 steps to complete one complete turn. However, the lowest step angle that can be taken with the stepper motors is 0.9°, requiring 400 steps to complete a turn. This increases the distance the motor travels, which allows for more accurate movements. Additionally, the motor’s RPM should include the range from 0 to 50 RPM. For that, the NEMA 23 198.2 in.-oz will be used. The maximum rotation is 400rpm. The speed range expected to be used is 12.5% of the motor's rated speed and has a maximum current per phase of 1.5A. The digital stepper driver used has a current per phase of 0.3-2.2A. Since the current per phase of the motor is in the range of the driver, the driver would be applicable. It has a maximum temperature of 50 °C, exceeding the incubator’s temperature. Furthermore, the maximum step resolution is one hundredth, allowing the driver to divide a complete step into 100 smaller steps. This enhances the variation in increments between the angles in the prototype, thereby enabling a broader range of inclination solutions. Using Eq. 4, the number of steps per revolution is 40,000, with a step angle of 0.009 °.

Total Microsteps= (360*(Step Resolution)^(-1))/(Full Step Angle) (4)

Regarding the inclination plane rotation, the most critical aspect is to ensure that during the stationary motion of the plane, the motor remains stationary. For that, Eq. 5 would be used to calculate the holding torque.

τ=m*g*d (5)

Where:

τ = torque

m = mass

d= perpendicular distance from the pivot

The mass of the components acting during the rotation of the motor would be divided into two main components: the acrylic incline plane and the bioreactor with its motor. The acrylic plane has a length of 0.127m, a width of 0.1524 m, a thickness of 0.00635m, and a density of 1190(kg)/(m^3) , the distance from the pivot point is 0.0635m. As for the bioreactor and motor, their total mass is the sum of 0.08kg and 0.28kg, with 0.0508m from the pivot. Additionally, to ensure safety, a safety factor of 2 would be used. For this, the holding torque is calculated to be 0.542 Nm. Since the camera component was not taken into consideration due to the unknown mass, the acceptable holding torque would be about 0.55-0.6 Nm.

The E Series Nema 17 Bipolar 42Ncm has a maximum holding torque of 0.55Nm. Since the holding torque is on the edge of a high approximated torque, the motor could be suitable. The maximum temperature is 50 °C, exceeding the incubator’s temperature. Additionally, the motor has a current rate per phase of 1.50A and has a step angle of 1.8°. Considering that this component is a stepper motor, a stepper driver has been selected to facilitate more precise rotational movement. The digital stepper driver used has a current per phase of 0.3-2.2A. Since the current per phase of the motor is in the range of the driver, the driver would be applicable. It has a maximum temperature of 50 °C, exceeding the incubator’s temperature. Furthermore, the maximum step resolution is one hundredth, allowing the driver to divide a complete step into 100 smaller steps. This enhances the variation in increments between the angles in the prototype, thereby enabling a broader range of inclination solutions.

The Nema 23 173.5 in-oz has a maximum holding torque of 1.225 Nm. Since the holding torque exceeds the maximum opposing torque, the motor is suitable. The maximum temperature reaches 266 °F (130 °C), exceeding the incubator's temperature limit. Additionally, the motor has a current rate per phase of 2.8A and has a step angle of 1.8°. Considering that this component is a stepper motor, a stepper driver has been selected to facilitate more precise rotational movement. The digital stepper driver used has a current per phase of 2.35-8A. Since the current per phase of the motor is in the range of the driver, the driver would be applicable. It has a maximum temperature of 85 °C, exceeding the incubator’s temperature. Furthermore, the maximum step resolution is one hundredth, allowing the driver to divide a complete step into 100 smaller steps. This enhances the variation in increments between the angles in the prototype, thereby enabling a broader range of inclination solutions.

Since there are two options for this motor, we are currently opting for the NEMA 17, as it is readily available. Additionally, since they both have the same wiring, driver, and Arduino library, if the NEMA 17 did not work, we would replace it with the NEMA 23, which we know would exceed the maximum torque of the prototype. Due to cost limitations, we would rather go with the NEMA 17.

2. L- Bracket for Motor Support

We need to hold the motor securely against a sturdy surface to prevent it from moving as it rotates. The other part of the L-bracket would be connected to the base of the prototype.

3. Motor Stepper Driver

The driver is used to let the motor know how fast or slow or in which direction we want it to go. Additionally, it adds more resolution in the steps, having smaller steps per rotation.

4. Motor to Shaft Coupler

Ensures a precise and secure connection between motors and shafts, reducing vibration and misalignment.

5. Ball Bearing

It is 0.5 inches in diameter, matching the diameter of the rod. Provides smooth rotational motion of the shaft and reduces friction. Additionally, the ball bearing provides stability and facilitates easy mounting.

6. Mounted Ball Bearing

It is 0.5 inches in diameter, matching the diameter of the rod. This would hold the free end of the rod.

7. Shaft Support

They will be connecting the rod to the plane. Two is used to ensure stability on both sides of the plane.

8. Acrylic sheet (0.5-inch, 0.25-inch)

Acrylic sheets shall be utilized as the foundational material for the prototype. Given that the prototype will be positioned within the incubator and the tests are anticipated to be conducted therein, the humidity and temperature within the incubator are likely to influence the base material of the prototype. The physical properties of the acrylic sheets, as determined by the ASTM method D648, show that a thickness of 0.236mm has a deflection temperature under a load of 264 psi of 99 °C, and the forming temperature ranges from 170 to 190 °C. The softening point, as determined by the ASTM method D1525, is 115 °C, with a maximum recommended continuous service temperature of 82 °C. Since the incubator would have a temperature significantly lower than the temperatures stated above, the minimum width of the acrylic sheets would be 0.236mm. Additionally, the electrical properties of the acrylic are those of a good insulator, with a surface resistivity higher than that of most plastics, making it a viable protector of the electrical components in the prototype.

9. Camera

Enables real-time visualization of bioreactor operations and conditions. An essential part of our needs. (Holding on to the purchase because it is dependent on the bioreactor)

The following parts should be revised with the advisors and anyone who was involved in Dr. Michael’s thesis to ensure the materials match the requirements. Parts needed are highlighted.

The acrylic used is a 3/16-inch cast acrylic that has already been purchased by one of our team members. The use of acrylic (and the functionality of the bioreactor) was based on replicating the bubble-catcher bioreactor designed by Dr. Michael Phelan. The acrylic parts would be the front plate, the back plate, and the central/bubble ring. The bioreactor requires a gas-permeable membrane, which will be made using the Tegaderm (medical silicone) on a thin nylon mesh (providing structural support) and pressed together. To ensure the bioreactor does not leak, a 0.5mm silicone rubber sheet is used, two sheets per bioreactor. The bioreactor requires 8 4x16M bolts with one nut, two washers, and one spring washer. A 5/8'' x 11 nut will be attached to the back to connect to the bioreactor rotating system. Before pressing the Tegaderm and nylon mesh, the methylene chloride will be used on the nylon mesh to weld the 5/8'' x 11 nut to the back plate of the bioreactor. The contact cement would be used to hold the nylon nut in place on the acrylic piece. The front plate will be pre-tapped using a quarter-inch tap and then fitted with ¼’’-28 screw-to-male Luer adapters. Two stopcocks for the inlet and one standard cap for emptying and cleaning will be connected in the pre-tapped holes. A compression Luer fitting will be used to fill and empty the bubble catch channel. To ensure accuracy, the adapter fitting, caps, and bolts/washers will be reviewed by Temple University labs to verify if the specific sizing are present. Otherwise, adjustments may be made if the sizes are not found. (Vendors found are MadeInChina, so we might need the sites that sell such components).

1. Biocompatible Resin

If the bolts don’t work, there is a high possibility that we will buy them. (If we are going to 3D “highly unlikely”, it will be used).

Parts/Supplies Already Purchased/ Gifted by Temple:

1. Aluminum Rod Shaft

13 inches in length and 0.5 inches in diameter. Serves as the primary rotating shaft connecting the motor to the apparatus.

2. Cell Culture Supplies

It is needed for validation (a negotiable requirement).

3. Alginate Beads Supplies

It is needed for validation (a non-negotiable requirement).

4. Tachometer

It is needed to validate the RPM, and fortunately, it will be provided by the university.

5. Square Bracket (x2)

Height: 1.53 inches

Length: 1.57 inches

Diameter: 0.5 inches

(will 3D print)

6. L Bracket (x6)

It is needed to hold the acrylic pieces together.

7. Arduino Uno Rev 2 Wi-Fi

This is the microcontroller that connects the “commands” to the driver.

8. Plastic for 3D printing

It is necessary to 3D-print the shaft coupler connecting the motor to the bioreactor (the bioreactor has its own connector) and the square brackets.

M5x20 with M5 hex head nuts (need 18)

M5 x25 (need 8)

M3 x 12 with M3 hex head nuts (need 16)

All nails and bolts are required to screw parts together.

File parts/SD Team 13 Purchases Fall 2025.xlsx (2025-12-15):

Supplier | Item Requested | Item Part # | URL | Quantity | Item Price | Total | Shipping Estimate
Grainger | Acrylic Sheet (0.5 in) | N/A | 0.5 in acrylic sheet (https://www.grainger.com/product/1ZAJ4?gclsrc=aw.ds&gad_source=1&gad_campaignid=21375667808) | 1 | 29.62 | 29.62 | 4 days
McMaster-Carr | Aluminum Easy-Access Base-Mounted Shaft Support (1/2') | 1865K3 | https://www.mcmaster.com/1865k3/ | 2 | 28.2 | 56.4 | 2-3 days
McMaster-Carr | Mounted Ball Bearing | 2820T36 | https://www.mcmaster.com/2820T36/ | 1 | 25.14 | 25.14 | 2 days
McMaster-Carr | Ball Bearing | 4668K6 | https://www.mcmaster.com/4668K6/ | 1 | 30.3 | 30.3 | 1 day
Amazon | Motor (NEMA 23) to Shaft Coupler | N/A | 6.35mm to 12.7mm Plum Flexible Shaft Coupling, Diameter 30mm Length 35mm Aluminium Motor Connector Flexible Spider Coupler for 3D Printer CNC Machine Servo Stepped Motor: Amazon.com: Industrial & Scientific (https://www.amazon.com/Flexible-Coupling-Diameter-Aluminium-Connector/dp/B0DLGQPJY4?s=industrial) | 1 | 9.19 | 9.19 | 2 day prime
Amazon | Motor (NEMA 17) to Shaft Coupler | N/A | 5mm to 12.7mm Plum Flexible Shaft Coupling, Diameter 30mm Length 35mm Aluminium Motor Connector Flexible Spider Coupler for 3D Printer CNC Machine Servo Stepped Motor: Amazon.com: Industrial & Scientific (https://www.amazon.com/Flexible-Coupling-Diameter-Aluminium-Connector/dp/B0DLGSB45C?s=industrial) | 1 | 10.39 | 10.39 | 2 day prime
McMaster-Carr | Luer Lock | 51525K223 | https://www.mcmaster.com/51525k223/ | 1 | 9.26 | 9.26 | 1 day
US America | Camera+ 64 GB Card | N/A | Mini WIFI Camera 1080P HD with Night Vision Included (https://usamerica.shop/product/mini-wifi-camera-1080p-hd-with-night-vision-included/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) | 1 | 39.9 | 39.9 | 4-5 business days
 |  |  |  |  | PRICE TOTAL | 210.2
 |  |  |  |  | MAX TOTAL | 1000
 |  |  |  |  | LEFT | 789.8

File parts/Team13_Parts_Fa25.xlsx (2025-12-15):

 | Thank you so much for everyone who is in charge of ordering and reviewing <3 !! We would love to see you at our final presentation :D (Nov. 20!)
Key |  | Surpassing $100 | Color Code | Part Needed For? | Item Requested | Supplier | Item Part # | URL | Quantity | Item Price |  | Total | Shipping Estimate | When to Order/ Need?
 | Please Buy (thank you)
 | Already in Temple | FALSE |  | Visualization | Camera+ 64 GB Card | US America | N/A | Mini WIFI Camera 1080P HD with Night Vision Included (https://usamerica.shop/product/mini-wifi-camera-1080p-hd-with-night-vision-included/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) | 1 | 39.9 |  | 39.9 | 4-5 business days | Holding the order (have to ensure the bioreactor first)
 | Hold Purchasing (until further notice)
 | Please Check if In Temple | FALSE |  | Prototype Base | Acrylic Sheet (0.25 in) | Home depot | 241610 | Home depot (https://www.homedepot.com/p/OPTIX-18-in-x-24-in-x-0-220-1-4-in-Clear-Acrylic-Sheet-MC-21/202038050) | 1 | 36.98 |  | 36.98 | Coming Sunday | Holding the order (already bought but might need more)
 | Holding the order to double check with advisor
 |  | FALSE |  | Prototype Base | Acrylic Sheet (0.5 in) | Grainger | N/A | 0.5 in acrylic sheet (https://www.grainger.com/product/1ZAJ4?gclsrc=aw.ds&gad_source=1&gad_campaignid=21375667808) | 1 | 29.62 |  | 29.62 | 4 days | As soon as possible (might need more in case anything goes wrong)
 |  | FALSE |  | Prototype Base | Plastic for 3D Printing | Temple University | N/A | N/A | 0 | 0 |  | 0 | Already Present | As soon as possible
 |  | FALSE |  | Prototype Base | M5x20 with M5 hex head nuts | Teaching Lab | N/A | N/A | 18 | 0 |  | 0 | Already present | As soon as possible
 |  | FALSE |  | Prototype Base | M5 x25 | Teaching Lab | N/A | N/A | 8 | 0 |  | 0 | Already present | As soon as possible
 |  | FALSE |  | Prototype Base | M3 x 12 with M3 hex head nuts | Teaching Lab | N/A | N/A | 16 | 0 |  | 0 | Already present | As soon as possible
 |  | FALSE | Purchased :D | Prototype Base | Aluminum Rod | Amazon | N/A | N/A | 1 | 0 |  | 0 | Coming Sunday | As soon as possible
 |  | FALSE |  | Prototype Base | Aluminum Easy-Access Base-Mounted Shaft Support (1/2') | McMaster-Carr | 1865K3 | https://www.mcmaster.com/1865k3/ | 2 | 28.2 |  | 56.4 | 2-3 days | As soon as possible
 |  | FALSE |  | Prototype Base | Mounted Ball Bearing | McMaster-Carr | 2820T36 | https://www.mcmaster.com/2820T36/ | 1 | 25.14 |  | 25.14 | 2 days | As soon as possible
 |  | FALSE |  | Prototype Base | Ball Bearing | McMaster-Carr | 4668K6 | https://www.mcmaster.com/4668K6/ | 1 | 30.3 |  | 30.3 | 1 day | As soon as possible
 |  | TRUE |  | Prototype Base | Stepper Motor For Rod | McMaster-Carr | 6627T53 | https://www.mcmaster.com/6627T53/ | 1 | 111.68 |  | 111.68 | 2 days | Holding the order (will try with the other motor first)
 |  | FALSE |  | Prototype Base | Motor (NEMA 23) to Shaft Coupler | Amazon | N/A | 6.35mm to 12.7mm Plum Flexible Shaft Coupling, Diameter 30mm Length 35mm Aluminium Motor Connector Flexible Spider Coupler for 3D Printer CNC Machine Servo Stepped Motor: Amazon.com: Industrial & Scientific (https://www.amazon.com/Flexible-Coupling-Diameter-Aluminium-Connector/dp/B0DLGQPJY4?s=industrial) | 1 | 9.19 |  | 9.19 | 2 day prime | Holding the order (will try with the other motor first)
 |  | FALSE |  | Prototype Base | L-bracket (Motor Support) | StepperOnline | ST-M2 | Nema 23 Bracket for Stepper Motor and Geared Stepper Motor Alloy Steel Bracket - ST-M2 | StepperOnline (https://www.omc-stepperonline.com/nema-23-bracket-for-stepper-motor-and-geared-stepper-motor-alloy-steel-bracket-st-m2) | 2 | 4.09 |  | 8.18 | Within 24 hours | As soon as possible
 |  | FALSE |  | Prototype Base | Stepper Motor For Rod | Temple University | N/A | N/A (NEMA 17) | 1 | 0 |  | 0 | Already Present | As soon as possible
 |  | FALSE |  | Prototype Base | Motor (NEMA 17) to Shaft Coupler | Amazon | N/A | 5mm to 12.7mm Plum Flexible Shaft Coupling, Diameter 30mm Length 35mm Aluminium Motor Connector Flexible Spider Coupler for 3D Printer CNC Machine Servo Stepped Motor: Amazon.com: Industrial & Scientific (https://www.amazon.com/Flexible-Coupling-Diameter-Aluminium-Connector/dp/B0DLGSB45C?s=industrial) | 1 | 10.39 |  | 10.39 | 2 day prime | As soon as possible
 |  | FALSE |  | Prototype Base | L-bracket (Motor Support) | Temple University | N/A | N/A | 1 | 0 |  | 0 | 2-3 days prime | As soon as possible
 |  | TRUE |  | Prototype Base | Stepper Motor for Bioreactor | McMaster-Carr | 6627T242 | https://www.mcmaster.com/6627T242/ | 1 | 135.86 |  | 135.86 | 2 days | As soon as possible
 |  | FALSE |  | Prototype Base | Stepper Driver | Temple University | N/A | N/A | 2 | 0 |  | 0 | Already Present | As soon as possible
 |  | FALSE |  | Bioreactor | Silicone Gasket | Amazon | N/A | Amazon.com: Translucent Silicone Rubber Sheet - High Temp Silicone Gasket, 0.5mm to 30mm Thickness, Versatile Use, 1pc(50x50x0.5mm) : Industrial & Scientific (https://www.amazon.com/dp/B0FFYVQ7MZ) | 1 | 24.32 |  | 24.32 | 2 weeks | As soon as possible
 |  | FALSE |  | Bioreactor | PDMS Silicone | Amazon | N/A | Yufreyoo PDMS Silicone Film Sheet for Bio-Chips and Packaging, 200mm x 150/300mm, 300m, Transparent, Elastic, Low Modulus: Amazon.com: Industrial & Scientific (https://www.amazon.com/Silicone-Transparent-Electronic-Substrate-microfluidic/dp/B0CQX5B4T5?s=industrial) | 1 | 29.99 |  | 29.99 | 2 weeks | As soon as possible
 |  | FALSE |  | Bioreactor | Nylon Mesh Fabric | Amazon | N/A | Amazon.com: OTGMGCB Nylon Mesh Fabric, 60 80 100 120 200 250 300 350 400 500 Mesh Filter, Reusable Strainer Cloth for Wine Juice Fresh Milk(1m x 1m) (400 mesh) : Industrial & Scientific (https://www.amazon.com/OTGMGCB-Fabric-Filter-Reusable-Strainer/dp/B0F29XXS3L) | 1 | 15.99 |  | 15.99 | 2 days prime | As soon as possible
 |  | FALSE |  | Bioreactor | Methyline Chloride | Thermo Fisher | 113460010 | Dichloromethane, 99.8+%, for analysis, stabilized with amylene 1 L | Buy Online (https://www.thermofisher.com/order/catalog/product/113460010) | 1 | 44.65 |  | 44.65 | Unknown (needs temple account) | As soon as possible
 |  | FALSE |  | Bioreactor | Tegaderm | Amazon | N/A | Amazon.com: 3M tegaderm Roll 2" x 11Yd Transparent Film Dressing (Each), # 16002 : Health & Household (https://www.amazon.com/3M-Tegaderm-Transparent-Dressing-16002/dp/B006I4JZM6?th=1) | 1 | 19.99 |  | 19.99 | 2 weeks | As soon as possible
 |  | FALSE |  | Bioreactor | Contact Cement | Amazon | N/A | Clear-Tite Contact Cement, 4 oz. can - Laminate Flooring, Countertops, Tabletops, Crepe Rubber, Ceramics, Wood Veneers, Waterproof, Long Lasting - RH Adhesives: Amazon.com: Industrial & Scientific (https://www.amazon.com/RH-Adhesives-Clear-Tite-Contact-Cement/dp/B09FF3XWQL?adgrpid=1338106221347223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) | 1 | 12.99 |  | 12.99 | 5 days | As soon as possible
 |  | FALSE |  | Bioreactor | Quart-inch Tap | McMaster-Carr | 2521A771 | Uncoated High-Speed Steel Tap Set, 1/4"-20 UNC | McMaster-Carr (https://www.mcmaster.com/2521A771/) | 1 | 18.74 |  | 18.74 | 2 days | As soon as possible
 |  | FALSE |  | Bioreactor | Biocampatible resin | MatterHackers | M-WTC-9J7J | Liqcreate Resin for LCD & DLP 3D Printers (https://www.matterhackers.com/store/l/liqcreate-resin-for-lcd-dlp-3d-printers-bio-med-clear/sk/MWTC9J7J) | 1 | 55 |  | 55 | 2-3 days | Holding the order (would purchase if the bolts did not work for the bioreactor / plan B)
 |  | FALSE |  | Validation | Tachometer | Teaching Lab | N/A | N/A | 0 | 0 |  | 0 | Already present | In two weeks maximum
 |  | FALSE |  | Validation | Alginate Beads Supplies | Teaching Lab | N/A | N/A | 0 | 0 |  | 0 | Already present | In two weeks maximum
 |  | FALSE |  | Validation | Cell Culture Supplies | Teaching Lab | N/A | N/A | 0 | 0 |  | 0 | Already present | In two weeks maximum
 |  |  |  |  |  |  |  |  |  |  | PRICE TOTAL | 715.31
 |  |  |  |  |  |  |  |  |  |  | MAX TOTAL | 1000
 |  |  |  |  |  |  |  |  |  |  | LEFT | 284.69

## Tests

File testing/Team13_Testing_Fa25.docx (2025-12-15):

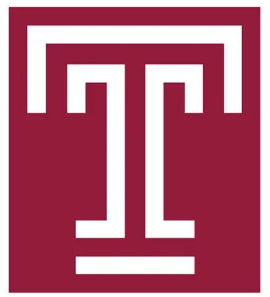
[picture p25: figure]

Temple University

# College of Engineering

# Bioengineering

Testing (only section)

Partial Gravity Bioreactor

Presented By: Team #13

Dmitry M Hackel | Irene Bui
Jake Fisher | Zenub Abouzid

Supervised By:

Dr. Yah-el Har-el & Dr. Peter Lelkes

10 – 19 – 2025

# Test Method

To guarantee the validity of the results and decisions, specific tests must be conducted.

## 1. Inclination Angle Test

To attain the necessary gravitational conditions for the prototype—including Earth, Mars, Lunar, and Micro-gravity environments—the inclination angle of the plane is meticulously adjusted. Consequently, precise determination of the inclination angle corresponding to each specific gravitational type is of paramount importance. Furthermore, given that the inclination adjustment may be repeated multiple times, ensuring the repeatability and accuracy of the angle measurements is critical. An inclination angle test has been conducted to evaluate both the accuracy and repeatability of the adjustments. Due to the absence of standardized procedures for such tests, a protocol has been developed. As the prototype is anticipated to operate within an incubator during testing, environmental factors such as temperature and air quality are maintained at consistent levels, thereby minimizing errors and variability attributable to environmental fluctuations.

The inclination angle is measured from the incubator's horizontal surface to the inclination plane movement to the intended angle (the inclination angle). Measurements commenced from an initial inclination of 0 degrees, with recorded values taken incrementally across predefined target angles (0°, 5°, 10°, 20°, 45°, 90°). At each configuration, the tilt was adjusted using the tilt code in the motor connected to the rod. To ensure the rotation of the bioreactor does not affect or cause a lag, each angle was run at different RPM values (0 rpm, 5 rpm, 10 rpm, and 20 rpm). The side-view videos of the prototype were captured with a phone camera for all the runs. The videos were recorded transitioning from 0 degrees to each target angle and back to zero, to evaluate hysteresis through positive and negative rotations. Subsequently, MATLAB code was employed to process these videos, determining the angle between the incubator's horizontal reference plane and the inclined plane. The use of video recording, as opposed to static images, ensured a smooth transition between angles and maintained flow stability within the bioreactor. At each position, three measurements were taken to assess repeatability. A total of 144 runs will be run. The design of the inclination angle test experiment table is seen in Supplementary S T 1.

The 0 degrees for each run were tested and compared to one another to ensure that the 0 degrees had not shifted during the runs. All data were recorded in a single session with the phone stabilized by a sturdy object placed on a surface. The deviation was calculated by determining the difference between the intended angle and the measured angle. The standard deviation for each repetition was also calculated. Linearity was assessed by plotting the measured angles against the observed angles. The mean error and repeatability were calculated for each position. The total uncertainty was estimated by finding the variance using an R function. The acceptable ranges of errors are ±0.01° to 0.3°. Errors would include the vibration of the prototype, vibration of the incubator, vibration caused by the bioreactor, and the weight of the material inside the bioreactor. All the statistics will be run in R.

## 2. RPM Test

One of the most critical components of the prototype is to ensure that the particles are suspended within the fluid and subjected to the intended gravitational forces. Since the bioreactor is designed to rotate smoothly to maintain a steady flow and provide a stable environment for the particles, the RPM must remain constant. Furthermore, as the combination of RPM and inclination determines the effective gravity acting on the particles, the RPM must be precise. An RPM test will be conducted to verify accuracy and ensure a steady flow.

Using a wireless digital tachometer, the RPM of the rotating bioreactor will be measured at the specified RPMs of 0, 5, 10, 15, 20, and 30 RPM. For each RPM, five measurements will be recorded at 30-second intervals to verify the consistency of the RPM within the flow. To ensure the stability of the digital tachometer, a phone stand will be used to support the device, and the angle of the bioreactor will be maintained perpendicular to the horizontal surface. A total of 90 runs will be performed. The design of the RPM test experiment table is presented in Supplementary S T 2.

The measurements shall be documented utilizing JMP software. For each RPM, three trials will be conducted to evaluate repeatability. The mean, standard deviation, and variance will be calculated using R. The permissible error margins are within ±0.1 rpm. Linearity was assessed by plotting the measured RPM against the observed RPM. Errors considered may include vibrations from the prototype and bioreactor, as well as factors such as air quality, temperature, and the mass of materials within the bioreactor. All statistical analyses will be performed using R.

## 3. Validation of Size

Given the constraints in the prototype's dimensions, the size is a critical parameter requiring precise measurement. Accordingly, the dimensions of the prototype will be measured three times weekly over two weeks after its construction. Temperature will be recorded during each measurement session. For each day of data collection, three measurements will be conducted to assess repeatability. These measurements will encompass length, width, and height at 0- and 90-degree angles. The mean, standard deviation, and variance will be computed using R. The measurements will be deemed acceptable if they are below the specified threshold, 21 × 17 × 14 in , which corresponds to the measurements of the internal space within the incubator.

## 4. Validation of Electrical Safety

Regarding the safety of the electrical component, the International Electrotechnical Commission (IEC), specifically IEC 60204-1, which delineates the general requirements for electrical machinery equipment, will serve as the basis for safety validation. According to 'Safety of Machinery - Electrical Equipment of Machines - Part 1: General Requirements’, a protective bonding circuit is mandated to ensure that all exposed metallic parts of the machinery are properly bonded and grounded [1]. This requirement encompasses electrical enclosures and wiring, which should be systematically organized, clearly labeled, and adequately protected, with cables rated appropriately for the voltage and current they conduct [1]. Compliance with EN 61010-2-030, Measuring Circuits and Test Equipment Safety Test, ensures adherence to the standard [2]. A multimeter will be employed to verify the current and voltage flow through components, ensuring their compliance. Furthermore, the visual inspection of wiring will be conducted to assess its integrity. The validation process will be performed weekly to guarantee user safety and the stability of electrical circuits. No statistical testing will be conducted.

## 5. Validation of Fluid Dynamics Using Alginate Beads

To validate the partial-gravity bioreactor and fluid dynamics, alginate beads can be added to visualize the motion of particles. Developed from a calcium chloride solution, they have similar densities to that of a cell. Due to the increased size of alginate beads, the bioreactor would have to run at 15 rpm [3]. This validation will directly influence whether it is possible to culture cells within the bioreactor.

Alginate beads are produced by dropwise adding a (w/v) aqueous mix of 0.75% sodium alginate, 1% polyethylene oxide, and 2% powdered charcoal (or fluorescence dye) for color into a stirred 2% calcium chloride bath [3]. The shear values were obtained using a computer modeling program (ANSYS). The position of the bead is measured using MATLAB code. A video of three trials for the alginate beads in each gravitational condition will be recorded using a camera setup of the prototype. At the beginning of each trial, an image of the alginate bead will be taken, with another picture taken at the end of a 30-minute simulated run. Using ImageJ, the circularity of the beads will be calculated using the total perimeter and the area in the images taken [3]. Measuring the circularity would ensure the flow is steady and does not affect the particles. The measurements will be calculated three times to ensure repeatability. The mean, standard deviation, and variation of each gravitational condition will be calculated using R. The circulatory is expected to be closer to 1, showing little to no change in the dimensions of the beads.

## 6. Cytotoxic Direct Contact Test

With the bioreactor being built from scratch, the materials that are in contact with the cells should be tested to ensure they are biocompatible and do not produce any leaches. This ensures that the cells are in their most favorable environment and conditions. According to the ISO 10993-5: Tests for In Vitro Cytotoxicity, three tests could be run [4]. It ensures that the substance used would not cause deformation or lysis of the cells beneath or around it. It is evaluated microscopically and then graded. The protocol is the following [5]:

- L929 cells (ATCC No. CCL1, NCTC clone 929 (connective tissue mouse), clone of strain L(DSMZ)) are grown at 37 °C in a 5% (v/v) CO2 incubator in DMEM supplemented with 10% (v/v) fetal bovine serum
- A 30mg sample of the material was placed into an empty well of a six-well culture plate.
- The cells were seeded into the well at a density of 50,000 cells per well.
- The plate was incubated at 37 °C for 24 hours
- The visual cytotoxicity was visualized using a microscope
- The score was assigned according to a 5-point scale, ranging from 1 to 5, with 1 showing cytotoxicity present and 5=no cytotoxicity. Figure 1 shows the visualization of the scale.
- To ensure the scores are accurate, three different wells will be tested.

The positive prediction is that the item would meet requirements if the test score of the response to the item were not greater than grade 2 (mildly reactive) [6].

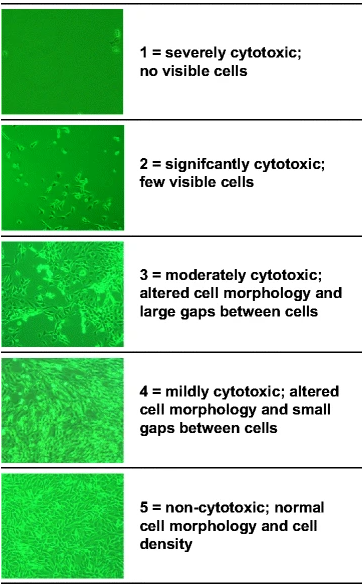
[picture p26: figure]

Figure 1. Cytotoxicity Scale Visualization

The figure shows the scheme for assigning visual cytotoxicity scores to biomaterials.

# References

1) “ISO 13850:2015,” ISO. Available: https://www.iso.org/standard/59970.html
2) “IEC 61010-2-030:2023,” IEC. Available: https://webstore.iec.ch/en/publication/75915
3) M. A. Phelan, A. L. Gianforcaro, J. A. Gerstenhaber, and P. I. Lelkes, “An Air Bubble-Isolating Rotating Wall Vessel Bioreactor for Improved Spheroid/Organoid Formation,” Tissue Engineering Part C Methods, vol. 25, no. 8, pp. 479–488, Jul. 2019, doi: 10.1089/ten.tec.2019.0088. Available: https://pmc.ncbi.nlm.nih.gov/articles/PMC6686703/?term=%22Tissue%20Eng%20Part%20C%20Methods%22%5Bjour%5D#SD1
4) “ISO 10993-5:2009,” ISO. Available: https://www.iso.org/standard/36406.html
5) S. K. Bhatia and A. B. Yetter, “Correlation of Visual In Vitro Cytotoxicity Ratings of Biomaterials With Quantitative In Vitro Cell Viability Measurements,” Cell Biology and Toxicology, vol. 24, no. 4, pp. 315–319, Oct. 2007, doi: 10.1007/s10565-007-9040-z. Available: https://doi.org/10.1007/s10565-007-9040-z
6) “Direct Cell Contact Test - Eurofins Medical Device Testing,” Eurofins Scientific. Available: https://www.eurofins.com/medical-device/testing/cytotoxicity-testing/direct-cell-contact-test/

# Supplementary Data

## Supplementary ST 1: Design of Inclination Angle Test Experiment (for 1 Trial)

Direction | RPM | 0 | 5 | 10 | 20
| Angle
Forward | 0 | 00F | 50F | 100F | 200F
| 5 | 05F | 55F | 105F | 205F
| 10 | 010F | 510F | 1010F | 2010F
| 20 | 020F | 520F | 1020F | 2020F
| 45 | 045F | 545F | 1045F | 2045F
| 90 | 090F | 590F | 1090F | 2090F
Reverse | 0 | 00R | 50R | 100R | 200R
| 5 | 05R | 55R | 105R | 205R
| 10 | 010R | 510R | 1010R | 2010R
| 20 | 020R | 520R | 1020R | 2020R
| 45 | 045R | 545R | 1045R | 2045R
| 90 | 090R | 590R | 1090R | 2090R

The table shows the design of the experiment for the inclination angle test. There are three factors: RPM, Angle, and Direction. The levels are the following: RPM (4 levels), Direction (2 levels), and Angle (6 levels). There are 48 runs for each trial, and since there are three trials, there is a total of 144 runs.

## Supplementary ST 2: Design of RPM Test Experiment (for 1 Trial)

Time | 0 | 30s | 1min | 1:30min | 2min
RPM
0 | 00 | 0.50 | 10 | 1.50 | 20
5 | 05 | 0.55 | 15 | 1.55 | 25
10 | 010 | 0.510 | 110 | 1.510 | 210
15 | 020 | 0.515 | 115 | 1.515 | 215
20 | 020 | 0.520 | 120 | 1.520 | 220
30 | 030 | 0.530 | 130 | 1.530 | 230

The table shows the design of the experiment for the RPM test. There are two factors: RPM and Time. The levels are the following: Time (5 levels) and RPM (6 levels). There are 30 runs for each trial, and since there are three trials, there is a total of 90 runs.

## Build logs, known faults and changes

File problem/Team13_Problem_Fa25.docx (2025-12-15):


Temple University

# College of Engineering

Bioengineering

Problem Statement

Partial Gravity Bioreactor

Presented By: Team #13

Dmitry M Hackel | Irene Bui
Jake Fisher | Zenub Abouzid

Supervised By:

Dr. Yah-el Har-el & Dr. Peter Lelkes

09 – 01 – 2025

Table of Contents

# 2. Overall Objective

Since the 1960s, space exploration has yielded intriguing discoveries that continue to unfold over time. Yuri Gagarin became the first human in space in 1961, paving the way for thousands of astronauts and cosmonauts to follow him as the years passed [1 (https://www.nasa.gov/image-article/april-1961-first-human-entered-space/)]. Various theories have been proposed based on space explorations, including the Croatian Barrel Theory, which explains how the solar system, stars, and other celestial bodies formed [2 (https://books.google.com/books?hl=en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)][3 (https://www.miromikelaus.com/)]. In 2002, research refuted the theory that gravity alone governs the universe, as it could not explain specific astronomical observations [4 (https://www.livescience.com/strange-theories-about-the-universe.html)]. Sanders and McGaugh modified Newtonian gravity as an alternative to cosmic dark matter, known as Modified Newtonian Dynamics (MOND), correlating a relationship between the acceleration from Newtonian gravity and the observed acceleration at any radius in a galaxy [5 (https://www.annualreviews.org/content/journals/10.1146/annurev.astro.40.060401.093923)][6 (https://arxiv.org/abs/2501.17006)].

Exploring space not only shows discoveries that are external to our planet, but it also uncovers truths that enhance and govern our lives. Advanced Combustion via Microgravity Experiments (ACME) investigates fuel efficiency and pollutant production in combustion under microgravity conditions on Earth [7 (https://www.nasa.gov/missions/station/iss-research/studying-combustion-and-fire-safety/)]. One of their investigations, Flame Design, studied the quantity of soot produced under different flame conditions [7 (https://www.nasa.gov/missions/station/iss-research/studying-combustion-and-fire-safety/)]. Such a discovery could lead to more efficient combustion, reducing pollution on Earth [7 (https://www.nasa.gov/missions/station/iss-research/studying-combustion-and-fire-safety/)]. In the ongoing Moon exploration, researchers found that the Moon's gravity affects Earth’s tides, plant growth, animal behavior, and agricultural practices [8 (https://papers.ssrn.com/sol3/papers.cfm?abstract_id=5090101)]. Moreover, models have shown that the Earth-Moon coupled magnetospheres provide a buffer against the solar wind, allowing for a reduction in Earth’s atmospheric loss to space [9 (https://pmc.ncbi.nlm.nih.gov/articles/PMC10763664/)]. The National Aeronautics and Space Administration (NASA) has been exploring Mars for over sixty years to decide whether it is or was a habitable world [10 (https://science.nasa.gov/planetary-science/programs/mars-exploration/)]. Since Mars is the most similar planet to Earth in the Solar System, understanding its surface and evolution is crucial for preparing for future human exploration [11 (https://www.esa.int/Science_Exploration/Human_and_Robotic_Exploration/Exploration/Why_go_to_Mars)]. With evidence suggesting that Mars was once full of water, warmer, and had a thicker atmosphere, it is highly likely that Mars could be a habitable environment [11 (https://www.esa.int/Science_Exploration/Human_and_Robotic_Exploration/Exploration/Why_go_to_Mars)].

Despite the profound findings, many questions remain unanswered. However, traveling outside the Earth’s atmosphere to explore potential extraterrestrial life is a risky and expensive endeavor. Given our bodies' high dependence on gravity, any significant change in gravity would cause severe issues [12 (https://link.springer.com/article/10.1007/s00421-025-05773-7)]. With that, it is highly unethical to send people into space without understanding the effects of partial gravity on the body, especially given the current state of technological advancements. In this paper, a proposed prototype of a device that cultures cells under the influence of partial gravity and microgravity is addressed, allowing for the correlation of certain cell behaviors with the gravitational difference.

# 3. Background

Understanding the effects of partial gravity on humans is less studied due to the high costs associated with conducting tests in a partial or microgravity environment. Between 1960 and 1973, the research experience and studies gained during the Apollo missions, which focused on lunar exploration, provided valuable information summarizing the different effects of partial gravity on the human musculoskeletal, cardiovascular, and respiratory systems, using either microgravity or Earth’s gravity as control [13 (https://www.nasa.gov/missions/apollo/apollo-15-mission-details/)][14 (https://www.frontiersin.org/journals/physiology/articles/10.3389/fphys.2017.00583/full)]. However, the Apollo missions cost $25.4 billion in 1969, equivalent to roughly $217 billion in 2024 [15 (https://apollo11space.com/apollo-program-costs-new-data-1969-vs-2024/)]. In 2019, the health impact of a year-long mission in space was examined in molecular and psychological traits by comparing the DNA sequence of the twin brothers – Mark and Scott Kelly – with Mark Kelly staying on Earth, “the control,” and Scott Kelly going to space [16 (https://www.science.org/doi/10.1126/science.aau8650)][17 (https://www.nasa.gov/humans-in-space/twins-study/)]. The study revealed that extensive multisystem and gene expression changes occur in spaceflight [16 (https://www.science.org/doi/10.1126/science.aau8650)].

Due to cost and ethical concerns, researchers aimed to simulate partial gravity on Earth, such as using a pulley-spring system to simulate partial gravity for rats [18 (https://pmc.ncbi.nlm.nih.gov/articles/PMC9472129/)]. However, one of the limitations of the apparatus was that the tail was suspended rather than the whole body, which would provide a weight shift in the rodent’s body, thereby not providing a “true” simulation [18 (https://pmc.ncbi.nlm.nih.gov/articles/PMC9472129/)].

Aiming for the least unethical approach, cell culturing is the most favorable approach, with bioreactors being the most suitable device, as they provide controlled nutrients and biomimetic stimulus deliveries for cell growth [19 (https://pmc.ncbi.nlm.nih.gov/articles/PMC5931275/)]. NASA developed a unique bioreactor to address the challenge of treating injured astronauts in space, where medical resources are limited [20 (https://spinoff.nasa.gov/Spinoff2009/hm_3.html)]. In microgravity, the bioreactor enables cells to grow in three-dimensional tissue structures that closely resemble natural development, facilitating advances in medicine both on Earth and in space [20 (https://spinoff.nasa.gov/Spinoff2009/hm_3.html)]. The success of NASA’s bioreactor shows how gravity influences biology. Microgravity fosters unique cell growth environments, while partial gravity (such as on the Moon and Mars) may present entirely different effects [21 (https://www.nature.com/articles/nm0397-259b)].

Partial gravity bioreactors, although not extensively studied, have been investigated previously. Research dating back to the 1900s has examined the effects of clinostats, or rotating wall vessels, on biologics [22 (https://www.researchgate.net/publication/365143869_Clinostats_and_Other_Rotating_Systems-Design_Function_and_Limitations)].

To understand the concepts that encompass partial gravity apparatuses, it is essential to differentiate between zero gravity, gravity, microgravity, and partial gravity. Zero gravity (0g) refers to the lack of gravitational force on an object due to its infinitely far distance from another gravitational object or the net sum of all forces acting on the object equaling zero [23 (https://www.oxfordlearnersdictionaries.com/definition/english/zero-gravity)]. Gravity is an abstract phenomenon that can be quantified, but the fundamental cause remains unknown [24 (https://www.britannica.com/science/gravity-physics)]. The gravitational constant ( G ) is not a force or acceleration but is utilized as a scaling factor for Newton's Law of gravitation, shown in Eq. 1 [24 (https://www.britannica.com/science/gravity-physics)].

F=(Gm_1 m_2)/(r^2) (Eq.1)

The impacts of gravity on an object can be either displacement or deformation [25 (https://www.sciencedirect.com/science/article/pii/S0734743X22003141)]. Microgravity refers to a condition where the net gravitational force acting on an object is minimal, typically within the range of 10⁻⁴ to 10⁻⁶g [26 (https://www.nasa.gov/centers-and-facilities/glenn/what-is-microgravity/)]. They are still affected by the forces of gravity but are in continuous free fall [26 (https://www.nasa.gov/centers-and-facilities/glenn/what-is-microgravity/)]. Partial gravity refers to the gravitational force that is reduced but not eliminated compared to the force of gravity on Earth, ranging from 0.1g to 0.4g, such as that on the Moon (0.16g) and Mars (0.38g) [17 (https://www.nasa.gov/humans-in-space/twins-study/)]. On Earth, partial gravity can be simulated through centrifugation, parabolic flight, or modified rotation devices that produce acceleration lower than 1g [27 (https://www.nature.com/articles/s41526-018-0041-4)]. Understanding the varying gravitational conditions is essential for space exploration and medical applications.

Prior bioreactors were developed as ground-based to approximate aspects of weightlessness or reduced gravity that a biological organism experiences in space. Many early partial gravity bioreactors tested their impact by using plant species, which can constantly grow against the gravitational forces found on Earth [28 (https://www.researchgate.net/publication/354358925_Understanding_Reduced_Gravity_Effects_on_Early_Plant_Development_Before_Attempting_Life-Support_Farming_in_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)]. Early renditions included clinostats, which continuously rotate a sample so that the gravitational vector is effectively averaged to near zero [22 (https://www.researchgate.net/publication/365143869_Clinostats_and_Other_Rotating_Systems-Design_Function_and_Limitations)]. This rendition of a partial gravity bioreactor cannot fully replicate “true” freefall since cells still experience mechanical stimulation and gradients that differ from the actual microgravity environment [22 (https://www.researchgate.net/publication/365143869_Clinostats_and_Other_Rotating_Systems-Design_Function_and_Limitations)]. Later, rotating wall vessel (RWV) bioreactors were introduced as a specialized form of clinostats [22 (https://www.researchgate.net/publication/365143869_Clinostats_and_Other_Rotating_Systems-Design_Function_and_Limitations)]. RWVs are fluid-filled cylinders containing cells that create a low-shear, controlled environment, allowing for cellular differentiation in three-dimensional space [29 (https://www.nature.com/articles/nm0898-901)]. By rotating at a terminal velocity, RWVs ensure proper nutrient delivery to the tissue culture, thereby promoting healthy tissue and cell growth [29 (https://www.nature.com/articles/nm0898-901)].

# 4. Needs Statement

The progress of human exploration to space, the Moon, and Mars is not considered safe due to the limited understanding of how partial gravity affects human cells, nor has it been fully addressed due to cost limitations and the inability to simulate partial gravity on Earth accurately. Building a partial gravity cell culturing prototype would enable the study of the relationship between cell properties and different gravitational environments, therefore allowing for human exploration without health complications.

# 5. Implications of Project Success

In case of the prototype's success, both life in space and on land would be enhanced. Understanding how different gravitational environments influence cells would provide more informed conclusions for human explorations. With such findings, solutions would be developed to ensure the safety of humans beyond Earth. Having humans travel to space, including Mars and the Moon, increases the information we have about outer space and helps answer questions about extraterrestrial life. It could potentially unlock new planets or locations in space where humans can start a new life.

The prototype’s success is based on the United Nations Sustainable Development Goals (UNSDG) [30 (https://unric.org/en/united-nations-sustainable-development-goals/)]. A Sustainable Development Goal (SDG) addressed is Life on Land (Goal #15), focusing on ensuring the safety of nature on our planet [31 (https://unric.org/en/sdg-15/)]. The prototype would primarily concentrate on combating desertification by collecting soil from other planets or studying the Moon’s role in enhancing agricultural methods. Another SDG addressed is Industry, Innovation, and Infrastructure (Goal #9), which focuses on promoting sustainable industrialization and fostering innovation [32 (https://unric.org/en/sdg-9/)]. With the ability to travel outside Earth, there would be increased innovations, whether by drugs or technologies, to allow humans to compensate for the gravitational difference. This would not only be required for a limited time, but there would also be a constant need to produce new vital drugs and technologies to sustain human life. For SDGs #12 and #13, the success of the prototype would promote sustainable strategies for space and Earth by demonstrating how biology adapts to reduced gravity and sustains life in space [33 (https://sdgs.un.org/goals/goal12)][34 (https://sdgs.un.org/goals/goal13)]. Finally, SDG #3, which refers to “good health and wellbeing,” the prototype’s success could benefit health and biology in space travel conditions by demonstrating the gravitational effects on cellular development [35 (https://sdgs.un.org/goals/goal3)]. If the potential of life outside Earth is true, such a prototype would address all the goals stated above.

# 6. References

1) “April 1961 - First human entered space - NASA,” NASA. Available: https://www.nasa.gov/image-article/april-1961-first-human-entered-space/
2) “Croatian Barrel Theory,” Google Books. Available: https://books.google.com/books?id=6fpgEQAAQBAJ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
3) “Croatian Barrel Theory | Miro (Mike) Laus,” Mike Laus. Available: https://www.miromikelaus.com/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,system%2C%20with%20celestial%20bodies%20emerging%20at%20varying%20times.
4) A. May, “10 wild theories about the universe,” Live Science, Jul. 16, 2021. Available: https://www.livescience.com/strange-theories-about-the-universe.html
5) R. H. Sanders and S. S. McGaugh, “Modified Newtonian dynamics as an alternative to dark matter,” Annual Review of Astronomy and Astrophysics, vol. 40, no. 1, pp. 263–317, Sep. 2002, doi: 10.1146/annurev.astro.40.060401.093923. Available: https://doi.org/10.1146/annurev.astro.40.060401.093923
6) B. Famaey and A. Durakovic, “Modified Newtonian Dynamics (MOND),” arXiv.org, Jan. 28, 2025. Available: https://arxiv.org/abs/2501.17006
7) NASA, “Studying combustion and fire Safety - NASA,” NASA, Mar. 07, 2024. Available: https://www.nasa.gov/missions/station/iss-research/studying-combustion-and-fire-safety/
8) Gullari, Jeevan Kumar. (2025). The Impact of Moon Phases on Earth, Plants, and Humans: A Comprehensive Study from Project Alpha. 10.13140/RG.2.2.12235.71203. Available: https://papers.ssrn.com/sol3/papers.cfm?abstract_id=5090101
9) J. Green, D. Draper, S. Boardsen, and C. Dong, “When the Moon had a magnetosphere,” Science Advances, vol. 6, no. 42, Oct. 2020, doi: 10.1126/sciadv.abc0865. Available: https://pmc.ncbi.nlm.nih.gov/articles/PMC10763664/
10) A. Cermak, “Mars Exploration - NASA Science,” NASA Science, Aug. 01, 2025. Available: https://science.nasa.gov/planetary-science/programs/mars-exploration/
11) “Why go to Mars?” Available: https://www.esa.int/Science_Exploration/Human_and_Robotic_Exploration/Exploration/Why_go_to_Mars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,beyond%20Earth%20is%20a%20fundamental%20question%20of%20humankind.
12) J. T. Fisher, U. Ciuha, P. Denise, A. C. McDonnell, H. Normand, and I. B. Mekjavic, “The combined effects of artificial gravity, temperature, and hypoxia on haemodynamic responses and limb blood flow,” European Journal of Applied Physiology, Apr. 2025, doi: 10.1007/s00421-025-05773-7. Available: https://doi.org/10.1007/s00421-025-05773-7
13) NASA, “Apollo 15: Mission Details - NASA,” NASA, Sep. 29, 2023. Available: https://www.nasa.gov/missions/apollo/apollo-15-mission-details/
14) C. Richter, B. Braunstein, A. Winnard, M. Nasser, and T. Weber, “Human Biomechanical and Cardiopulmonary Responses to Partial Gravity – a systematic review,” Frontiers in Physiology, vol. 8, Aug. 2017, doi: 10.3389/fphys.2017.00583. Available: https://doi.org/10.3389/fphys.2017.00583
15) Apollo11Space, “Apollo Program Costs (New Data 1969 vs 2024),” Apollo11Space, Mar. 17, 2024. Available: https://apollo11space.com/apollo-program-costs-new-data-1969-vs-2024/
16) F. E. Garrett-Bakelman et al., “The NASA Twins Study: A multidimensional analysis of a year-long human spaceflight,” Science, vol. 364, no. 6436, Apr. 2019, doi: 10.1126/science.aau8650. Available: https://doi.org/10.1126/science.aau8650
17) “Twins Study - NASA,” NASA. Available: https://www.nasa.gov/humans-in-space/twins-study/
18) S. Zhang, T. Adachi, S. Zhang, Y. Yoshida, and A. Takahashi, “A new type of simulated partial gravity apparatus for rats based on a pully-spring system,” Frontiers in Cell and Developmental Biology, vol. 10, Aug. 2022, doi: 10.3389/fcell.2022.965656. Available: https://pmc.ncbi.nlm.nih.gov/articles/PMC9472129/
19) M. Stephenson and W. Grayson, “Recent advances in bioreactors for cell-based therapies,” F1000Research, vol. 7, p. 517, Apr. 2018, doi: 10.12688/f1000research.12533.1. Available: https://pmc.ncbi.nlm.nih.gov/articles/PMC5931275/
20) “NASA Bioreactors Advance Disease Treatments | NASA Spinoff.” Available: https://spinoff.nasa.gov/Spinoff2009/hm_3.html
21) J. Wong, “Cells in space,” Nature Medicine, vol. 3, no. 3, p. 259, Mar. 1997, doi: 10.1038/nm0397-259b. Available: https://www.nature.com/articles/nm0397-259b
22) Hasenstein, K. H., & Van Loon, J. J. W. A. (2022). Clinostats and other Rotating Systems—Design, Function, and Limitations. In River Publishers eBooks (pp. 147–156). https://doi.org/10.1201/9781003338277-17
23) “zero gravity noun - Definition, pictures, pronunciation and usage notes | Oxford Advanced Learner’s Dictionary at OxfordLearnersDictionaries.com.” Available: https://www.oxfordlearnersdictionaries.com/definition/english/zero-gravity
24) Cook, A. H, Nordtvedt, K. L, Faller, and J. E, “Gravity | Definition, Physics, & Facts,” Encyclopedia Britannica, Aug. 13, 2025. Available: https://www.britannica.com/science/gravity-physics/Newtons-law-of-gravity
25) J. Sánchez-Haro, I. Lombillo, and G. Capellán, “Simplified model to consider influence of gravity on impacts on structures: Experimental and numerical validation,” International Journal of Impact Engineering, vol. 173, p. 104474, Dec. 2022, doi: 10.1016/j.ijimpeng.2022.104474. Available: https://www.sciencedirect.com/science/article/pii/S0734743X22003141
26) NASA, “What is Microgravity? - NASA,” NASA, Jul. 25, 2023. Available: https://www.nasa.gov/centers-and-facilities/glenn/what-is-microgravity/
27) A. Manzano et al., “Novel, Moon and Mars, partial gravity simulation paradigms and their effects on the balance between cell growth and cell proliferation during early plant development,” Npj Microgravity, vol. 4, no. 1, Mar. 2018, doi: 10.1038/s41526-018-0041-4. Available: https://www.nature.com/articles/s41526-018-0041-4
28) F. J. Medina, A. Manzano, A. Villacampa, M. Ciska, and R. Herranz, “Understanding reduced gravity effects on early plant development before attempting Life-Support farming in the Moon and Mars,” Frontiers in Astronomy and Space Sciences, vol. 8, Sep. 2021, doi: 10.3389/fspas.2021.729154. Available: https://www.researchgate.net/publication/354358925_Understanding_Reduced_Gravity_Effects_on_Early_Plant_Development_Before_Attempting_Life-Support_Farming_in_the_Moo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
29) B. R. Unsworth and P. I. Lelkes, “Growing tissues in microgravity,” Nature Medicine, vol. 4, no. 8, pp. 901–907, Aug. 1998, doi: 10.1038/nm0898-901. Available: https://www.nature.com/articles/nm0898-901
30) “United Nations Sustainable Development Goals (SDGs),” UN Regional Information Centre for Western Europe, UNRIC. Available: https://unric.org/en/united-nations-sustainable-development-goals/
31) “Goal 15: Sustainably manage forests, combat desertification, halt and reverse land degradation, halt biodiversity loss,” UN Regional Information Centre for Western Europe, UNRIC. Available: https://unric.org/en/sdg-15/ (https://unric.org/en/sdg-15/?utm_source=chatgpt.com)
32) “Goal 9: Build resilient infrastructure, promote sustainable industrialization and foster innovation,” UN Regional Information Centre for Western Europe, UNRIC. Available: https://unric.org/en/sdg-9/ (https://unric.org/en/sdg-9/?utm_source=chatgpt.com)
33) “Goal 12 | Department of Economic and Social Affairs.” Available: https://sdgs.un.org/goals/goal12
34) “Goal 13 | Department of Economic and Social Affairs.” Available: https://sdgs.un.org/goals/goal13
35) “Goal 3 | Department of Economic and Social Affairs.” Available: https://sdgs.un.org/goals/goal3
